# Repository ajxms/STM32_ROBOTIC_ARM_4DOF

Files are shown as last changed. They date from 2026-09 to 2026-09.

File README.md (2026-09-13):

# STM32 4-DOF Robotic Arm: Custom Inverse Kinematics & Bare-Metal C

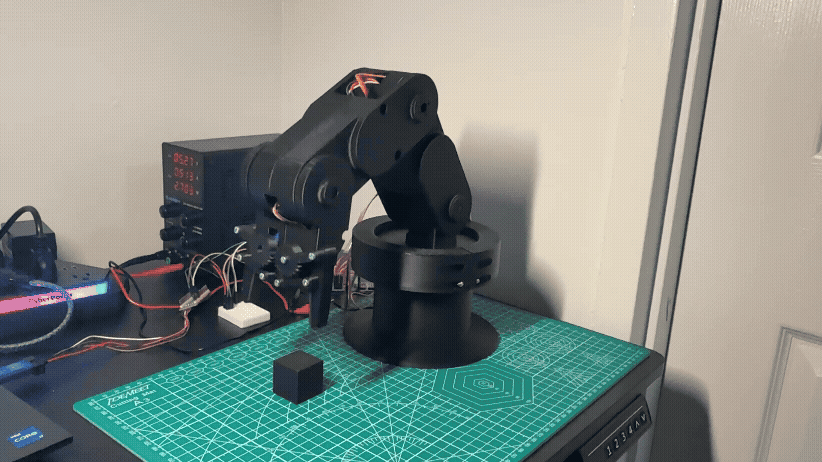
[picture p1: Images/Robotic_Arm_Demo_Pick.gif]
Robotic Arm Tracking Demo


## Project Overview
This project is a custom-engineered 4-Degrees-of-Freedom (DOF) robotic arm built entirely from scratch. Rather than relying on high-level microcontrollers (like Arduino) or pre-built kinematic libraries, this arm is driven by **bare-metal C on an STM32 microcontroller**. 

The goal was to build a complete hardware abstraction layer and a custom Cartesian Inverse Kinematics (IK) engine to achieve smooth, linear pick-and-place tracking.

**Watch the full video demonstration on my LinkedIn:** 

---

## Software Architecture & Kinematics

### 1. Custom Inverse Kinematics Engine
To move the arm to specific `(X, Y, Z)` coordinates, the software flattens the 3D space and calculates the exact joint angles in real-time.
* **Base Angle:** Calculated using `atan2(Y, X)` to determine the required rotation.
* **Shoulder & Elbow:** Implements the **Law of Cosines** to calculate the required angles to reach the hypotenuse distance to the target coordinate.
* **Dynamic Pitch:** The wrist angle is decoupled and interpolated separately, allowing the arm to "present" the payload at specific angles during transit.

### 2. Hardware Synchronization & Linear Tracking
The biggest challenge in servo robotics is mitigating jitter and non-linear arcs. 
* **PWM Refresh Locking:** The PCA9685 driver expects a 50Hz signal (20ms). The `HAL_Delay` inside the interpolation loop is dynamically reduced to exactly compensate for the mathematical execution time and the 100kHz I2C transmission overhead, eliminating dropped frames.
* **Linear Interpolation:** To move in a perfectly straight Cartesian line, the software calculates micro-waypoints at 1mm increments. The continuous pursuit forces the shoulder and elbow to dynamically adjust their curves, locking the payload onto a laser-straight path.

---

## Hardware & Electronics

* **Microcontroller:** STM32 Nucleo (STM32F411)
* **Servo Driver:** PCA9685 (communicating via I2C at 100kHz)
* **Actuators:** 5x Standard Hobby Servos
* **Power:** 5V 3A Power Bench Supply

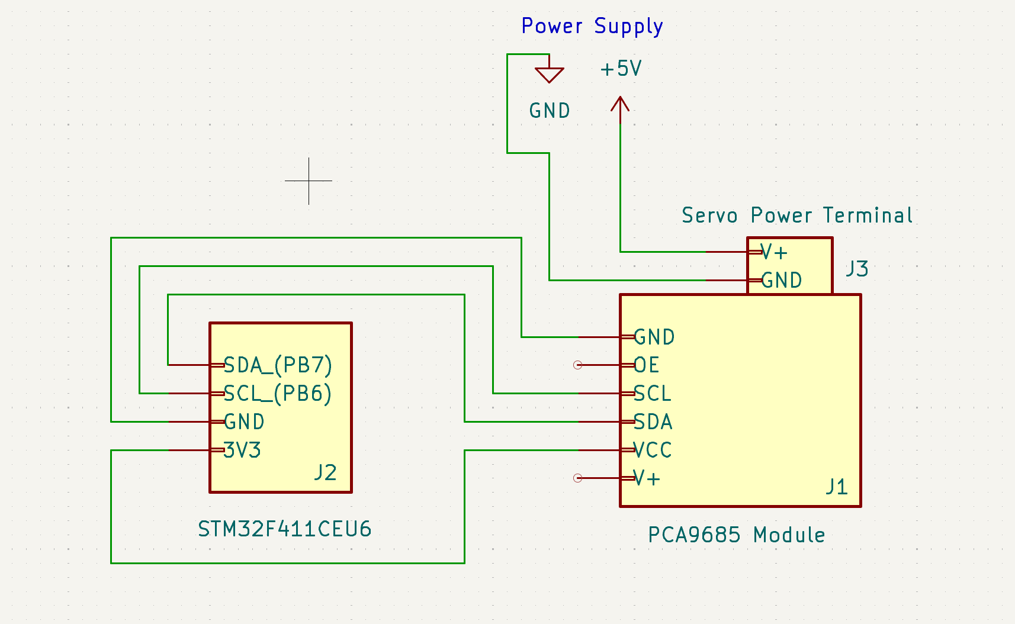
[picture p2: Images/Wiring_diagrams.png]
Wiring Schematic


---

## Mechanical Design & Fabrication

I custom-designed the entire robotic chassis and claw mechanism from scratch using **Autodesk Fusion 360**. Instead of using off-the-shelf mechanical kits, I engineered custom servo mounts, joint linkages, and structural arms with specific tolerances. 

The parts were rapid-prototyped and fabricated using PLA and PETG filaments on a Bambu Lab A1 Mini. 

All of my original mechanical files are open-source and provided in multiple formats for easy modification or direct printing:
* `.f3d` - Raw Fusion 360 archive (Parametric timeline intact)
* `.step` - Universal CAD assembly
* `.3mf` - Pre-oriented and sliced project file ready for fabrication

---

## Repository Structure

* **/Firmware:** The complete STM32CubeIDE project (bare-metal C, HAL configuration).
* **/CAD_and_Hardware:** Fusion 360 models, STEP files, and 3D printing assets.
* **/Images:** Media, GIFs and wiring diagrams used in this documentation.

---

## Future Improvements
* Implement dynamic collision avoidance to prevent self-intersection.
* Upgrade I2C transmission to 400kHz Fast Mode for tighter loop execution.
* Incorporate non-blocking hardware timers (`HAL_GetTick()`) to replace standard delays.

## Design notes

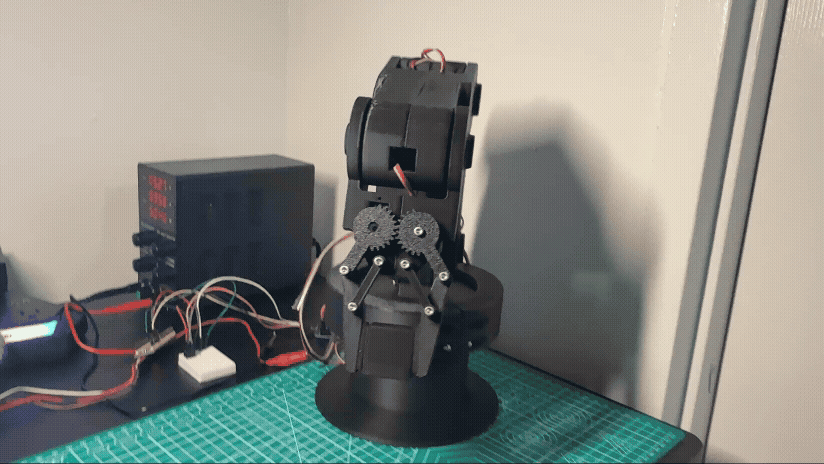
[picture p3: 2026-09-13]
Images/Robotic_Arm_Demo_Drop.gif

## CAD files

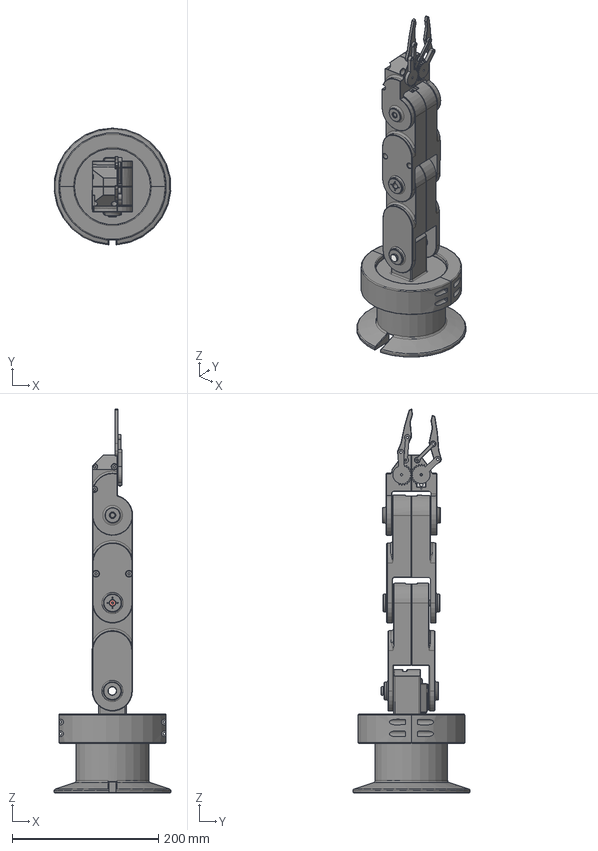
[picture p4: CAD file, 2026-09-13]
CAD_And_Hardware/4DOF_Robotic_Arm.step
159.4 x 159.8 x 525.3 mm

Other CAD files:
CAD_And_Hardware/4DOF_Robotic_Arm.3mf
CAD_And_Hardware/4DOF_Robotic_Arm.f3d

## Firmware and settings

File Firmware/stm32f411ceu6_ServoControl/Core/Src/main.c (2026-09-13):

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
/* Includes ------------------------------------------------------------------*/
#include "main.h"

/* USER CODE BEGIN Includes */
#include <math.h>

/* USER CODE END Includes */

/* USER CODE BEGIN PD */

#define PCA9685_ADDRESS 0x80 //original 7-bit address is 0x40 but bit shifted by 1 for 8-bits.
#define MODE1 0x00 //the main register where bits are manipulated to sleep or wake the chip.
#define PRESCALE_ADDRESS 0xFE
#define CHANNEL_REGISTER 0x06
#define claw_open 18
#define claw_close 136 //angle for opening and closing based on version 1

//measurements of the robot
#define L1 112.83
#define L2 112.75
#define L3 130
#define BASE_HEIGHT 140
#define RAD_TO_DEG 57.2957795
#define DEG_TO_RAD 0.01745329

// The starting home position of your arm
// The starting home position of your arm (Safe tall standby)
float current_x = 100.0;
float current_y = 0.0;
float current_z = 150.0;
float current_pitch = -90.0; // Add this so the arm remembers its wrist angle


/* USER CODE END PD */

I2C_HandleTypeDef hi2c1;

void SystemClock_Config(void);
static void MX_GPIO_Init(void);
static void MX_I2C1_Init(void);
/* USER CODE BEGIN PFP */
void PCA9685_init(I2C_HandleTypeDef *hi2c);
void PCA9685_setPWM(I2C_HandleTypeDef *hi2c, uint8_t servo_channel, uint16_t on_tick, uint16_t off_tick);
void PCA9685_SetServoAngle(uint8_t Channel, float Angle);
void setAllAngle(float waist, float shoulder, float elbow, float wrist, float claw);
void reachCoordinate(float x, float y, float z, float pitch_deg, float claw_angle);

/* USER CODE END PFP */

/* USER CODE BEGIN 0 */

//initialize the board by making it sleep, and applying prescale so that the information can be passed in a similar frequency
//that the servo wants.
void PCA9685_init(I2C_HandleTypeDef *hi2c){
	uint8_t sleep_mode = 0x10;
	uint8_t prescale_val = 121; //25MHz/(2^8 steps * target Hz (50 Hz) => 121
	uint8_t wake_mode = 0x20;

	//make the chip sleep before writing the prescaler.
	HAL_I2C_Mem_Write(hi2c, PCA9685_ADDRESS, MODE1, I2C_MEMADD_SIZE_8BIT, &sleep_mode, 1, 100);
	HAL_Delay(10);

	//write prescale
	HAL_I2C_Mem_Write(hi2c, PCA9685_ADDRESS, PRESCALE_ADDRESS, I2C_MEMADD_SIZE_8BIT, &prescale_val, 1, 100);
	HAL_Delay(10);

	HAL_I2C_Mem_Write(hi2c, PCA9685_ADDRESS, MODE1, I2C_MEMADD_SIZE_8BIT, &wake_mode, 1, 100);
	HAL_Delay(10);
}

//method that sends command to the channel registers
void PCA9685_setPWM(I2C_HandleTypeDef *hi2c, uint8_t servo_channel, uint16_t on_tick, uint16_t off_tick)
{
	uint8_t start_register  = CHANNEL_REGISTER + (4 * servo_channel);

	//store the date into an array
	uint8_t pwm_data[4];
	/*
	 * on low 0x06
	 * on high 0x07
	 * off low 0x08
	 * off high 0x09  This is for default channel of 0.
	 */
	pwm_data[0] = on_tick & 0xFF; //this cuts off the upper 8 bits out of 16 bits data.
	pwm_data[1] = (on_tick >> 8) & 0xFF; //this slides the data 8 bits to the right and cuts off the upper 8 bits so now its only 8 bits remaining
	pwm_data[2] = off_tick & 0xFF; //this cuts off the upper 8 bits out of 16 bits data.
	pwm_data[3] = (off_tick >> 8) & 0xFF;

	//send the data
	HAL_I2C_Mem_Write(hi2c, PCA9685_ADDRESS, start_register, I2C_MEMADD_SIZE_8BIT, pwm_data, 4, 100);
}

void PCA9685_SetServoAngle(uint8_t Channel, float Angle)
{
  float Value;
  // 50 Hz servo then 4095 Value --> 20 milliseconds
  // 0 degree --> 0.5 ms(102.4 Value) and 180 degree --> 2.5 ms(511.9 Value)
  uint16_t smallTick = 102.4;
  uint16_t bigTick = 511.9;
  Value = (Angle * (bigTick - smallTick) / 180.0) + smallTick;
  PCA9685_setPWM(&hi2c1, Channel, 0, (uint16_t)Value);
//  PCA9685_SetPWM(Channel, 0, (uint16_t)Value);
}

//helper to code all parts at once
void setAllAngle(float waist, float shoulder, float elbow, float wrist, float claw)
{
	PCA9685_SetServoAngle(0, waist);
	PCA9685_SetServoAngle(1, shoulder);
	PCA9685_SetServoAngle(2, elbow);
	PCA9685_SetServoAngle(3, wrist);
	PCA9685_SetServoAngle(8, claw);
}


void reachCoordinate(float x, float y, float z, float pitch_deg, float claw_angle)
{
	//base angle and reach
	float waist_angle_rad = atan2(y,x);
	float r = sqrt((x * x) + (y * y)); //reach distance from the center

	//values based on wrist
	float pitch_rad = pitch_deg * DEG_TO_RAD;
	float r_new = r - L3 * cos(pitch_rad); // r - x where x = right side from L3 -> pitch deg, this finds the new coordinate based on the length and angle
	float z_new = z - BASE_HEIGHT - (L3 * sin(pitch_rad)); // similar to the above where it finds a new coordinate.

	//check to see if the coordinate is reachable
	float invisible_length = sqrt( (r_new * r_new) + (z_new * z_new));
	if(invisible_length > L1 + L2) //checks if the invisible line from shoulder to coordinate is smaller than both length combined.
	{
		return; //Not possible.
	}

	//find the angles for the shoulder and elbow
	//shoulder
	float shoulder_angle1_rad = acos( ((L1 * L1) + (invisible_length * invisible_length) - (L2 * L2)) / (2 * L1 * invisible_length)); //law of cosines
	float shoulder_angle2_rad = atan2(z_new, r_new); //other angle
	float shoulder_angle_deg = (shoulder_angle1_rad + shoulder_angle2_rad) * RAD_TO_DEG;
	//elbow
	float elbow_angle_rad  = acos ( ((L1 * L1) + (L2 * L2) - (invisible_length * invisible_length)) / (2 * L1 * L2)); //law of cosines
	float elbow_angle_deg = 180 - (elbow_angle_rad * RAD_TO_DEG); //included 180 to get the angle with respect to shoulder.

	//wrist angle
	float wrist_angle_deg = pitch_deg - (shoulder_angle_deg - elbow_angle_deg);

	//Account for change in direction of angles

	//waist 0=CW, 90=Center, 180=CCW
	float servo_waist = 90.0 + (waist_angle_rad * RAD_TO_DEG);

	//shoulder 180 -> back 0 -> forward
	float servo_shoulder = shoulder_angle_deg;

	//elbow
	float servo_elbow = 90.0 + elbow_angle_deg;

	// Wrist: 0=Forward, 90=Straight, 180=Back
	float servo_wrist = 90.0 + wrist_angle_deg;

	//execute
	setAllAngle(servo_waist, servo_shoulder, servo_elbow, servo_wrist, claw_angle);
}

void smoothMoveTo(float target_x, float target_y, float target_z, float target_pitch, float claw_angle, int steps, int step_delay_ms)
{
    //Calculate how far to move in each direction per step
    float dx = (target_x - current_x) / steps;
    float dy = (target_y - current_y) / steps;
    float dz = (target_z - current_z) / steps;
    float dpitch = (target_pitch - current_pitch) / steps; //new pitch

    for (int i = 1; i <= steps; i++)
    {
        float step_x = current_x + (dx * i);
        float step_y = current_y + (dy * i);
        float step_z = current_z + (dz * i);
        float step_pitch = current_pitch + (dpitch * i);

        reachCoordinate(step_x, step_y, step_z, step_pitch, claw_angle);
        HAL_Delay(step_delay_ms);
    }

    //update the main memory
    current_x = target_x;
    current_y = target_y;
    current_z = target_z;
    current_pitch = target_pitch;
}


/* USER CODE END 0 */

/**
  * @brief  The application entry point.
  * @retval int
  */
int main(void)
{

  /* MCU Configuration--------------------------------------------------------*/

  /* Reset of all peripherals, Initializes the Flash interface and the Systick. */
  HAL_Init();

  /* Configure the system clock */
  SystemClock_Config();

  /* Initialize all configured peripherals */
  MX_GPIO_Init();
  MX_I2C1_Init();
  /* USER CODE BEGIN 2 */

  // If the PCA9685 does NOT respond, blink the PA8 LED rapidly and freeze
  if (HAL_I2C_IsDeviceReady(&hi2c1, PCA9685_ADDRESS, 3, 100) != HAL_OK) {
      while (1) {
          HAL_GPIO_TogglePin(GPIOA, GPIO_PIN_8);
          HAL_Delay(100);
      }
  }

  	PCA9685_init(&hi2c1);
	//Starting position
	reachCoordinate(current_x, current_y, current_z, current_pitch, claw_open);
	HAL_Delay(2000);
  /* USER CODE END 2 */

  /* Infinite loop */
  /* USER CODE BEGIN WHILE */
  while (1)
  {
    /* USER CODE END WHILE */

    /* USER CODE BEGIN 3 */
	  	  	//Hover directly over the 30mm cube
	        smoothMoveTo(150.0, 0.0, 100.0, -90.0, claw_open, 20, 15);
	        HAL_Delay(500);

	        //Drop to exactly Z=15 (center of the 30mm cube)
	        smoothMoveTo(150.0, 0.0, 25.0, -90.0, claw_open, 20, 20);
	        HAL_Delay(200);

	        //Snap the claw shut
	        PCA9685_SetServoAngle(8, claw_close);
	        HAL_Delay(800);

	        //Pull it straight up to clear the desk
	        smoothMoveTo(150.0, 0.0, 100.0, -90.0, claw_close, 20, 15);
	        HAL_Delay(500);

	        //Linear tracking
			// Moving 100mm -> 100 steps ensures a waypoint every 1 millimeter.
			smoothMoveTo(150.0, 100.0, 100.0, -90.0, claw_close, 100, 10);
			HAL_Delay(200);

			//moving 200mm (from 100 to -100) -> 200 steps to maintain 1mm resolution.
			smoothMoveTo(150.0, -100.0, 100.0, -90.0, claw_close, 200, 10);
			HAL_Delay(200);

			//Show the picked item to camera
			smoothMoveTo(150.0, 0.0, 120.0, -45.0, claw_close, 100, 10);
			HAL_Delay(1000); // Pause for the camera

			// diagonally also requires high steps to stay linear
			smoothMoveTo(50.0, 150.0, 100.0, -90.0, claw_close, 150, 10);
			HAL_Delay(500);

	        //Descend to Z=15 and release
	        smoothMoveTo(50.0, 150.0, 20.0, -90.0, claw_close, 20, 15);
	        HAL_Delay(200);
	        PCA9685_SetServoAngle(8, claw_open);
	        HAL_Delay(800);

	        //Return to Standby tall posture
	        smoothMoveTo(current_x, current_y, 150.0, -90.0, claw_open, 20, 15);
	        smoothMoveTo(100.0, 0.0, 150.0, -90.0, claw_open, 60, 15);

	        // Wait 3 seconds before repeating the showcase
	        HAL_Delay(1000);
//	        smoothMoveTo(100.0, 0.0, 150.0, -90.0, claw_open, 60, 15);
	        for(int  i = 0; i < 3; i++){
		        PCA9685_SetServoAngle(3, 90+45);
		        HAL_Delay(300);
		        PCA9685_SetServoAngle(3, 90-45);
		        HAL_Delay(300);
	        }
	        HAL_Delay(6000);


  }
  /* USER CODE END 3 */
}

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


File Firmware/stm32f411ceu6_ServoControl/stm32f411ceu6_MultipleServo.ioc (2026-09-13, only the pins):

Mcu.UserName=STM32F411CEUx
PA13.Signal=SYS_JTMS-SWDIO
PA14.Signal=SYS_JTCK-SWCLK
PA8.Signal=GPIO_Output
PB6.Signal=I2C1_SCL
PB7.Signal=I2C1_SDA

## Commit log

2026-09-13 Initial release: Custom IK and 3D CAD Files
    [4DOF_Robotic_Arm.3mf, 4DOF_Robotic_Arm.f3d, 4DOF_Robotic_Arm.step]
2026-09-13 Enhance README with project details and structure
    Added detailed project overview, software architecture, hardware specifications, and future improvements for the STM32 4-DOF robotic arm.
2026-09-13 Added robotic arm pick and drop gif
2026-09-13 Update README with mechanical design details
    I custom-designed the entire robotic chassis and claw mechanism from scratch using Autodesk Fusion 360. The parts were rapid-prototyped and fabricated using PLA and PETG filaments on a Bambu Lab A1 M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
2026-09-13 Added schematics
2026-09-13 Restore README.md content and update wiring schematic
2026-09-13 added image of wiring diagram for clear view
2026-09-13 Revise README with updated images and formatting
    Updated wiring schematic image and fixed formatting issues.

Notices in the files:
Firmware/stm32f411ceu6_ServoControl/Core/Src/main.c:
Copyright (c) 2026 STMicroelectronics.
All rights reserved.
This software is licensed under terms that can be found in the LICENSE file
